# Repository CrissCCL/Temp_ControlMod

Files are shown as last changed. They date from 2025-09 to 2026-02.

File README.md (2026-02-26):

# 🔥 Temperature Control Module
### From System Identification to Real-Time Embedded Control

🚀 **Featured by Arduino**  
[Read the official article](https://blog.arduino.cc/2026/02/26/from-theory-to-hardware-cristian-castro-lagos-on-control-engineering-with-arduino/)

Engineering-grade closed-loop temperature control platform integrating ARX system identification, digital PI controller design, deterministic real-time implementation, and experimental validation using Arduino Leonardo.







## 🔎 Why This Project Matters

This platform demonstrates the complete professional workflow used in real-world control system development:

Data acquisition → System identification → Controller design → Discretization → Embedded implementation → Experimental validation.

It bridges control theory with physical hardware under real sampling, saturation, and noise constraints.

## 📖 Overview
This low-cost module was designed and built to perform hands-on experiments in Digital Control. The system is controlled using an Arduino Leonardo, heat is modulated with a TIP31C transistor, and temperature is measured using a TMP36 sensor.  

It provides a simple and practical platform for learning control theory in a laboratory environment.

## 📂 Contents
- `/HardwareV2` → New Version schematic, Gerbers and BOM+POS for PCBA.
- `/Hardware` → schematic, PCB, Gerbers.
- `/control_temp_LC` → C code for Arduino.

## 🌐 YouTube
📺 [Part 1 [ES]](https://youtu.be/2oqOS14WYN8?si=qGYRzMjagaLqCLr8)

## 📊 Project Status

| Component | Status |
|---|---|
| Temperature Sensor Interface | ✅ Completed |
| Signal Filtering and Smoothing | ✅ Completed |
| PID Control Implementation | ✅ Completed |
| Migration from MATLAB Data Logging to Processing 4 GUI | ✅ Completed |
| Data Storage and CSV Export | ✅ Completed  |
| Processing 4 GUI (Monitoring & Logging) | ✅ Completed |
|  PCB Design with Improved Measurement Stability  | ✅ Completed |

> 💻 The project now features a Processing 4 graphical interface that replaces the previous MATLAB-based monitoring, data recording and data logging system.  
> 🔧 This new GUI allows real-time temperature monitoring and data recording, alongside the ongoing development of a custom PCB to improve measurement stability and reduce signal noise.

## ⚙️ System Description
- **Controller:** Arduino Leonardo or Mega  
- **Sensor:** TMP36 analog temperature sensor  
- **Actuator:** TIP31C transistor controlling a heating element  
- **Control Strategy:** Digital PI temperature regulation  
- **Sampling period:** 0.1 seconds  
- **Data transmission:** Serial communication for data logging and Processing 4 GUI monitoring  
- **PCB:** Custom-designed board for power and measurement stability  

## 🔄 Control Loop

<p align="center">
Diagrama sistema
</p>

### Controlled Variables
- **Temperature** → Temperature value control (stabilization)

## 📐 Digital PID Control

The PID controllers implemented in this project are **incremental (velocity form)** and use **trapezoidal integration** for the integral term.  
This ensures:
- Accurate discrete-time implementation suitable for microcontrollers.
- Consistency between simulation and embedded hardware behavior.
- Avoidance of integral windup when combined with actuator saturation or anti-windup mechanisms.

The Module uses a discrete PI controller implemented on a Arduino microcontroller.  
The control law in the digital domain is expressed as:

$$
u(n) = u(n-1) + K_0 e(n) + K_1 e(n-1)
$$

Digital PI controller implemented for temperature measured,

$$
V_{PWM}(n) = V_{PWM}(n-1) + K_0 e(n) + K_1 e(n-1)
$$

### Parameters:
The parameters are adjusted for temperature measured,

$$
K_0 = K_p + \frac{K_p}{2T_i} T_s
$$

$$
K_1 = -K_p + \frac{K_p}{2T_i} T_s
$$

## 🔉 Signal Processing: Low-Pass IIR Filter (1st Order)

To reduce measurement noise, a **first-order IIR low-pass filter** was applied to the temperature signal before feeding it to the controller and the ARX model.  

### 🔹 Filter Equation  

$$
y(k) =(1 - \alpha)  \cdot x(k) +  \alpha \cdot y(k-1)
$$  

Where:  
- $$x(k)$$: raw sensor measurement at time step $$k$$  
- $$y(k)$$: filtered output  
- $$\alpha$$: smoothing factor, $$(0<\alpha<1)$$ 

## 🧪 PI Control Test and ARX Model Comparison  

A test was performed using a **PI controller** applied to the temperature control module.  
The experimental results were compared against a **linear ARX model** identified from system data.  

### 🔹 General ARX Model Equation  

The ARX (Auto-Regressive with eXogenous input) model is defined as:  

$$
y(k) + a_1 y(k-1) + a_2 y(k-2) + \dots + a_{n_a} y(k-n_a) =
b_1 u(k-1) + b_2 u(k-2) + \dots + b_{n_b} u(k-n_b) + e(k)
$$  

Where:  
- $$y(k)$$: system output at sample $$k$$ 
- $$u(k)$$: input signal at sample $$k$$  
- $$( a_i, b_j)$$: ARX parameters  
- $$( n_a, n_b)$$: model orders  
- $$e(k) $$: disturbance/noise  

### 🔹 Results Overview  
- ✅ The PI controller improved **temperature tracking** and reduced overshoot.  
- 📉 The ARX model captured the main dynamics, with small discrepancies due to nonlinear heat transfer effects.  
- ⚖️ The comparison confirms the applicability of ARX models for **thermal system control design**.  

### 🔹 Experimental Plots  

<p align="center">
ARX vs Experimental Comparison (Temperature)
</p>

## 🖥️ GUI — Monitoring and Data Logging

The graphical user interface (GUI) shown in the photograph is developed using **Processing 4**.  
It is designed **only for monitoring** the temperature module in real time and for **recording experimental data**.  

<p align="center">
GUI preview
</p>

Key features:
- Real-time plot of temperature and setpoint.
- Display of control output (PWM or equivalent).
- Logging of measurements to files for offline analysis.
- Simple visualization of system behavior during experiments.

> ⚠️ **Note:** The GUI is for observation and data recording only; it does **not** modify the control system or send commands to the hardware.

> ⚠️ **Status:** Work In Progress — the GUI is being actively developed and will be added to the repository once sufficiently stable.

## 📉 Measurement Stability Improvement — PCB v2 vs PCB v3

The new PCB revision focused on improving the **temperature signal stability** without changing the control algorithm.

### 🔧 Issues Observed in PCB v2
In the previous revision, the temperature reading from the TMP36 sensor showed perturbations during heater actuation by the TIP31C transistor.  
This was mainly due to lack of proper analog stabilization near the sensor.

### ✅ Modifications Introduced in PCB v3
To address this, the following hardware changes were implemented according to TMP36 manufacturer guidelines:

- ✔ **Decoupling capacitor added** close to TMP36 power pins
- ✔ **Analog conditioning resistors changed to SMD**
- ✔ **All related passive components migrated to SMD footprint** to minimize parasitics and noise pickup

No changes were made to the controller firmware or sensor type — only the PCB-level conditioning was improved.

### 📊 Comparative Experimental Results

| Version | Condition | Plot |
|---|---|---|
| **PCB v2 (Old)** | Visible ripple & switching noise on temperature signal |  |
| **PCB v3 (New)** | Stable and smooth measurement — disturbances eliminated |  |

> ✅ The addition of the capacitor and SMD passives significantly reduced noise, improving the quality of temperature measurements and the overall stability of the closed-loop response.

## 🖼️ Render 3D PCB 

<table>
  <tr>
    <td align="center">
      PCB Render - Version 3<br>
      <sub>PCB Render - Version 3 - NEW VERSION </sub>
    </td>
    <td align="center">
        PCB Render - Version 2<br>
      <sub>PCB Render - Version 2- OLDER VERSION </sub>
    </td>
  </tr>
</table>

## ⚡ Physical Prototype

The updated PCB and system assembly have been tested successfully.  
The following image shows the complete setup of the **new prototype version**:

<p align="center">
  Complete Prototype Setup - Version 3
</p>

The following images show the complete setup of the **previous prototype version**:

<table>
  <tr>
    <td align="center">
      Foto del prototipo<br>
      <sub>Device connections</sub>
    </td>
    <td align="center">
      Foto del prototipo<br>
      <sub>Complete setup</sub>
    </td>
  </tr>
</table>

## 🔗 ROS 2 Integration

This embedded temperature control module can be connected to a ROS 2 system
for supervision, telemetry streaming, remote setpoint control and online metrics.

👉 **ROS 2 Bridge Repository:**  
[Ros integration](https://github.com/CrissCCL/Temp_ControlMod_ROS_integration)

The ROS integration provides:

- UART ↔ ROS 2 bridge
- Real-time topics (/temp, /u, /ref)
- Remote setpoint commands
- Online control performance metrics (IAE, ISE, ITAE, etc.)
- rosbag logging and visualization tools

This separation keeps:
- this repo → embedded/firmware/control
- ROS repo → middleware/supervision/integration

## 🔗 Related Repositories

For additional tutorials and examples related to digital control simulations, visit:

- [Digital Control — Anti-Windup (Positional PI)](https://github.com/CrissCCL/Digital_ControlAntiWindup)
- [Digital Control Simulation — First Order System + Saturation](https://github.com/CrissCCL/Digital_ControlSim)
- [Digital Control Simulation — ARX Model + Saturation](https://github.com/CrissCCL/Digital_ControlSimARX)

## 🤝 Support projects
 Support me on Patreon [https://www.patreon.com/c/CrissCCL](https://www.patreon.com/c/CrissCCL)

## 📜 License
MIT License

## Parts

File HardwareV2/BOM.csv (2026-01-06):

Reference | Qty | Value | DNP | Exclude from BOM | Exclude from Board | Footprint | Datasheet
C1 | 1 | C |  |  |  | Capacitor_SMD:C_1206_3216Metric_Pad1.33x1.80mm_HandSolder | ~
D1 | 1 | LED |  |  |  | LED_THT:LED_D5.0mm | ~
IC1 | 1 | TMP36GT9 |  |  |  | SamacSys_Parts:TMP36GT9 | https://www.analog.com/media/en/technical-documentation/data-sheets/TMP35_36_37.pdf
J1 | 1 | Conn_01x08_Socket |  |  |  | Connector_PinHeader_2.54mm:PinHeader_1x08_P2.54mm_Vertical | ~
Q1 | 1 | TIP31C |  |  |  | Package_TO_SOT_THT:TO-220-3_Vertical | https://www.centralsemi.com/get_document.php?cmp=1&mergetype=pd&mergepath=pd&pdf_id=tip41.PDF
R1,R2 | 2 | 470 |  |  |  | Resistor_SMD:R_1206_3216Metric_Pad1.30x1.75mm_HandSolder | ~

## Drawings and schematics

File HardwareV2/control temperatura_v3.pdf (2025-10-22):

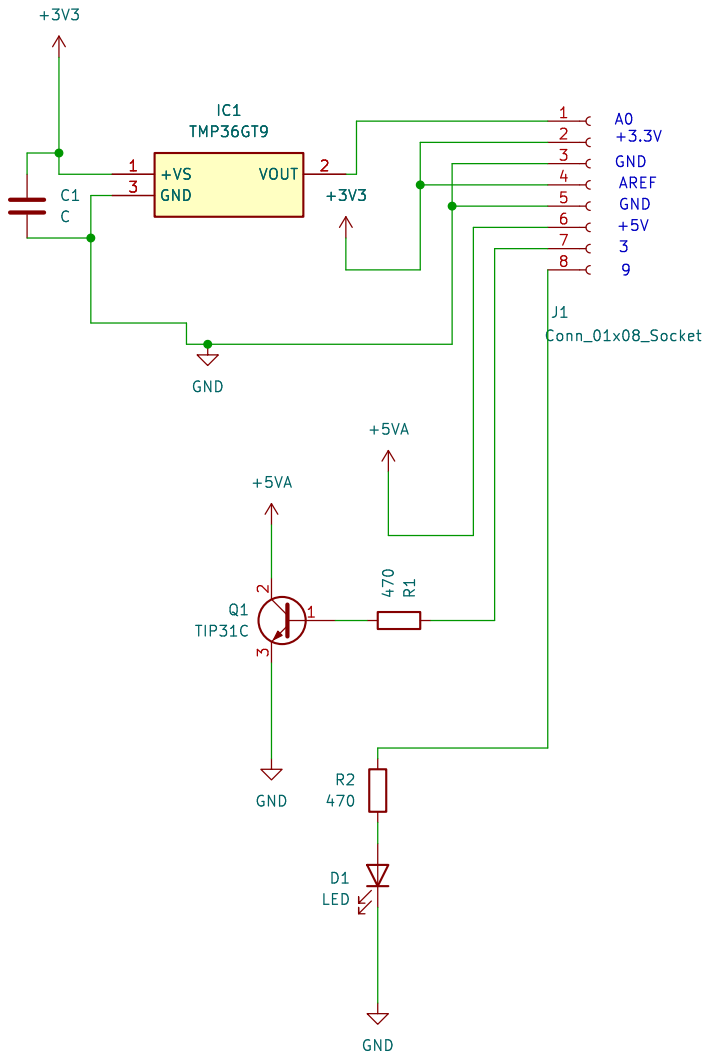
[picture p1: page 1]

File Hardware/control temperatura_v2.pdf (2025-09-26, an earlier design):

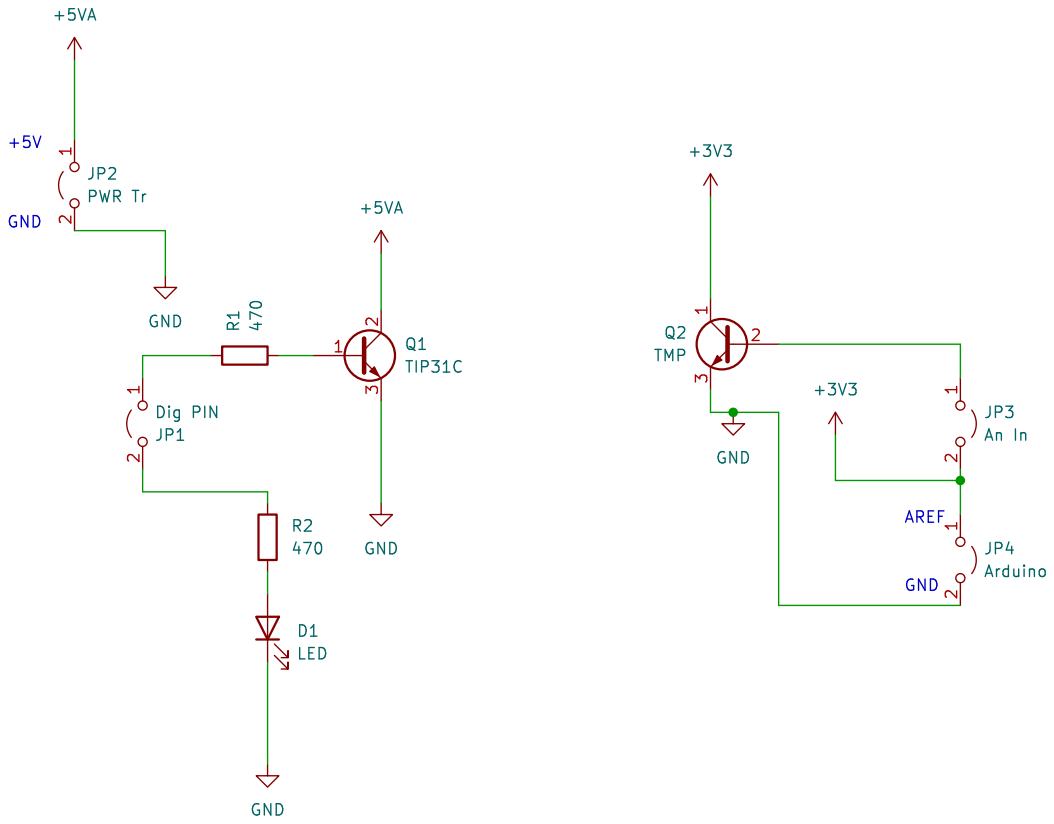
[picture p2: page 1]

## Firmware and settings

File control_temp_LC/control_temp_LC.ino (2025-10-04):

/*Control Temperatura*/
/*Cristian Castro Lagos*/
#include <Wire.h>
uint32_t LoopTimer;
int Pin =  9; //led que marca muestreo
float Temp; //Temperatura medida
float Temp_1=0.0;
float a=0.9391; // parametro filtro IIR
float ref=30.0;  //Referencia temperatura
float u=0.0,u_1=0.0;//Se_al de control
float e=0.0,e_1=0.0;// error resp
float K0=7.6634,K1=-7.6488; //parametros control PI discreto
float tiempo=0;
void setup() {
  Serial1.begin(57600);
  //Serial.begin(38400);
  pinMode(Pin, OUTPUT);
  ref=(float(analogRead(A0))*3.3/1023.0-0.5)/0.01;
  LoopTimer=micros();
}


void loop() {
  digitalWrite(Pin, !digitalRead(Pin));
  Temp = (1.0-a)*(float(analogRead(A0))*3.3/1023.0-0.5)/0.01+a*Temp_1; // fitro digital medicion temperatura
  Temp_1=Temp;
  if (tiempo>=200){
    ref=35.0;
  }
  e=(ref-Temp); //cierre de lazo de control  

  // Control PI
  u = u_1 + K0*e + K1*e_1; //controlador PI discreto
  if (u >= 100.0){      //saturacion
    u = 100.0;
  } 
  
  if (u <= 0.0 || ref==0.0){
    u = 0.0;
  }
  e_1=e;
  u_1=u;
  //control signal
  analogWrite(3,map(u,0,100,0,255));
  Serial1.print(Temp);  
  Serial1.print(","); 
  Serial1.print(u);
  Serial1.print(",");
  Serial1.print(ref);
  Serial1.print(",");
  Serial1.println(tiempo);
    while ( micros() - LoopTimer< 100000); // el codigo se bloquea o no avanza hasta que se cumpla la condicion
  LoopTimer=micros();
  tiempo=tiempo+0.1;
}

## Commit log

2025-10-22 Update README with new PCB Render - Version 2
    Added PCB Render - Version 2 image to the README.
2025-10-24 Adjust image widths for PCB comparison in README
    Updated image widths in comparative results section.
2025-10-24 Adjust image width for PCB v2 in README
    Updated image width for PCB v2 (Old) in comparative results.
